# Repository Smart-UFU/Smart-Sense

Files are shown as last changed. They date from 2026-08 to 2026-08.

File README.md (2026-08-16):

# Smart-Sense

An open-source, low-cost, 3D-printed **absorbance photometer (colorimeter)** built around an
ESP32-S3 microcontroller and an AS7341 multi-channel spectral sensor.

You put a standard cuvette in the well, press a button, and the device does what a benchtop
colorimeter does: it measures a blank, measures five standards of known concentration, fits a
calibration curve (Beer–Lambert), and then reports the concentration of unknown samples — at up to
**8 wavelengths simultaneously** (415, 445, 480, 515, 555, 590, 630 and 680 nm).

Everything is configured from a web page served by the device itself. No app, no cables, no
software to install on your phone or laptop *after* the device is built.

> **This guide assumes no electronics or programming experience.** If you can follow a lab
> protocol, you can follow this. The only step that involves a computer is Part 2 (flashing), and it
> is a copy-and-click procedure.

---

## Contents

- [What you need](#what-you-need)
- [Part 1 — Printing the parts](#part-1--printing-the-parts)
- [Part 2 — Putting the code into the ESP32 (flashing)](#part-2--putting-the-code-into-the-esp32-flashing)
- [Part 3 — Using the device](#part-3--using-the-device)
- [Part 4 — How the code works](#part-4--how-the-code-works)
- [Known limitations](#known-limitations)
- [License](#license)

---

## What you need

### Electronics

| Item | Notes |
|---|---|
| **Adafruit Feather ESP32-S3 Reverse TFT** (PID 5691) | The brain + the 240×135 colour screen + the three buttons. The firmware is compiled specifically for this board. |
| **Adafruit AS7341 10-Channel Light/Color Sensor breakout** (PID 4698) | The detector. It also carries the white LED used as the light source. |
| **STEMMA QT / Qwiic cable** (JST-SH 4-pin) | Connects the sensor to the Feather. Both boards have the connector, so **no soldering is required**. |
| **USB-C cable capable of carrying data** | Needed once, to flash the firmware. See the warning in [Part 2](#step-5--connect-the-board). |
| *(optional)* 3.7 V LiPo battery with JST-PH connector | Makes the device portable. Not required. |

### Consumables

| Item | Notes |
|---|---|
| **Standard cuvettes, 12.5 × 12.5 mm outside, 10 mm path length** | The well in the printed case measures **12.7 mm square**, i.e. a standard cuvette plus 0.2 mm clearance. Plastic (PMMA/PS) cuvettes are fine for visible-range work. |

### Hardware

| Item | Notes |
|---|---|
| 4 × M3 self-tapping screws, 8–10 mm | The mounting holes in the printed parts are **Ø2.8 mm**, so a thread-forming M3 screw cuts its own thread in the plastic. M2.5 machine screws also work. |

### Tools

- A **3D printer** (FDM/filament, any common model) — or access to a printing service.
- A **computer running Windows, macOS or Linux** for the flashing step.

---

## Part 1 — Printing the parts

All three files are in the [`3D PIECES TO PRINT/`](3D%20PIECES%20TO%20PRINT) folder. Print **one of
each**.

| File | What it is | Size (mm) | Supports? |
|---|---|---|---|
| [`espCase.stl`](3D%20PIECES%20TO%20PRINT/espCase.stl) | Main body: holds the electronics and contains the cuvette well | 78.8 × 67.1 × 50.0 | **Yes** |
| [`bottomPlate.stl`](3D%20PIECES%20TO%20PRINT/bottomPlate.stl) | Flat lid that closes the bottom of the body | 78.9 × 69.1 × 2.0 | No |
| [`screenCover.stl`](3D%20PIECES%20TO%20PRINT/screenCover.stl) | Thin frame that sits over the display | 60.8 × 32.9 × 3.0 | No |

Total print time is roughly **5–7 hours** and uses about **80–110 g** of filament, depending on
your printer and settings.

### ⚠️ The single most important printing rule

**Print in opaque black filament.**

This is not cosmetic. The device measures how much light a sample absorbs. Any light that leaks
through the walls of the case and reaches the sensor without passing through the cuvette is *stray
light*, and stray light makes absorbance readings read low and non-linear at high concentrations —
exactly where you least want an error.

Concretely:
- Use **black** PLA or PETG. Not white, not natural, not translucent, not "galaxy" or sparkle.
- Use at least **3 perimeters (walls)** and **4 top/bottom layers** so the shell is genuinely
  light-tight.
- Use at least **20 % infill**. Higher is fine.

If you hold the finished body up to a bright lamp and can see any glow through the walls, print it
again with more walls.

### Recommended slicer settings

These work in Cura, PrusaSlicer, Bambu Studio, Orca — any slicer.

| Setting | Value |
|---|---|
| Material | PLA (easiest) or PETG (more heat-resistant) |
| Colour | **Black, opaque** |
| Layer height | 0.2 mm |
| Walls / perimeters | 3 or more |
| Top / bottom layers | 4 or more |
| Infill | 20–30 % |
| Supports | **Only for `espCase.stl`** — "support on build plate only" is enough |
| Brim | Optional; helps if your bed adhesion is marginal |
| Nozzle | 0.4 mm (standard) |

### ⚠️ Orient the parts before slicing

`espCase.stl` and `bottomPlate.stl` were exported **tilted 30° relative to the build plate**. If you
drop them into the slicer and hit "slice" without looking, they will print leaning over, need
enormous amounts of support, and come out badly.

Fix it in one click:

1. Load the part.
2. Use your slicer's **"Place on face"** tool (Cura: `Lay flat` / `Place on face`;
   PrusaSlicer and Orca: `Place on face`, keyboard shortcut `F`).
3. Click the **large flat face** of the part — for `espCase.stl` this is the big open bottom, for
   `bottomPlate.stl` it is either of the two large flat faces.

If your slicer has no such tool, rotate the part **+30° around the X axis** manually. When it is
correct, the reported height will be **50.0 mm** for `espCase.stl` and **2.0 mm** for
`bottomPlate.stl`.

`screenCover.stl` is already flat and needs no rotation — just lay it with its large flat face down.

### After printing

- Check that the **cuvette well is clear**. It should be a clean 12.7 mm square opening; a cuvette
  should slide in with a light friction fit and no rocking. Remove any support material or stringing
  from inside it with a hobby knife.
- Check that the **light-path openings** — the small windows in the walls on either side of the
  well — are clear and square. The LED shines in through one side and the sensor looks in from the
  other, so any debris or stringing here corrupts your readings directly.
- Do **not** sand or polish the inside of the case. A matte black interior is what you want.

---

## Part 2 — Putting the code into the ESP32 (flashing)

"Flashing" just means copying the program onto the microcontroller. You do it once. After that the
device runs standalone, and you never need the computer again.

We use **Visual Studio Code** (a free code editor from Microsoft) plus **PlatformIO** (a free
extension that handles compilers and libraries automatically). PlatformIO downloads everything else
it needs by itself.

> **Time required:** about 10 minutes of clicking, plus 5–15 minutes of unattended downloading the
> first time.

### Step 1 — Install Visual Studio Code

1. Go to **<https://code.visualstudio.com/>**.
2. Download the installer for your operating system and run it.
3. Accept the defaults. On Windows, ticking *"Add to PATH"* is helpful but not required.

### Step 2 — Install the PlatformIO extension

1. Open Visual Studio Code.
2. On the left-hand vertical bar, click the **Extensions** icon (four small squares, or press
   `Ctrl+Shift+X` — `Cmd+Shift+X` on macOS).
3. Type **`PlatformIO IDE`** in the search box.
4. Click **Install** on the entry published by *PlatformIO*.
5. Wait. The first install pulls down a Python environment and takes several minutes. A progress
   notification appears in the bottom-right corner.
6. **Restart VS Code** when it asks you to. When PlatformIO is ready, a small **ant/alien head icon**
   appears in the left-hand bar and a **house icon** appears in the blue status bar at the bottom.

### Step 3 — Download this project

**Option A (no Git needed):**
1. On the project's GitHub page, click the green **`Code`** button → **`Download ZIP`**.
2. Unzip it somewhere easy to find, e.g. your Desktop or Documents folder.

**Option B (if you have Git installed):**

```bash
git clone https://github.com/Smart-UFU/Smart-Sense.git
```

> **Avoid folder names with accents, spaces or special characters** in the full path
> (`C:\Users\João\Área de Trabalho\...`). The compiler toolchain occasionally chokes on them. A path
> like `C:\Smart-Sense` is safest.

### Step 4 — Open the project (this is where most people go wrong)

You must open the **`CODE`** folder — **not** the top-level `Smart-Sense` folder.

PlatformIO recognises a project by the presence of a `platformio.ini` file, and that file lives
inside `CODE/`.

1. In VS Code: **File → Open Folder…**
2. Navigate into `Smart-Sense` and select the folder named **`CODE`**.
3. Click **Select Folder** / **Open**.
4. If VS Code asks *"Do you trust the authors of the files in this folder?"*, click **Yes, I trust
   the authors** — otherwise PlatformIO cannot run.

You will know it worked when the blue status bar at the bottom of the window grows extra icons: a
**✓ (checkmark)**, a **→ (right arrow)**, a **🗑 (trash can)** and a **🔌 (plug)**.

**The first time you open it, PlatformIO will download the ESP32 compiler toolchain and the four
required libraries.** This is several hundred megabytes and can take 5–15 minutes on a normal
connection. Let it finish — the progress appears in the terminal panel at the bottom. You need an
internet connection for this step only.

### Step 5 — Connect the board

Plug the Feather into your computer with a **USB-C cable**.

> ⚠️ **The most common failure in this whole guide is a charge-only USB cable.** Many cheap USB-C
> cables (especially the ones bundled with phone chargers and power banks) carry power but no data.
> The board will light up and appear dead to the computer. If nothing is detected, **try a different
> cable first** before doing anything else.

The ESP32-S3 has native USB, so on Windows 10/11, macOS and Linux **no driver installation is
normally needed**. The board shows up on its own.

### Step 6 — Build and upload

1. Click the **✓ (checkmark)** icon in the bottom status bar. This is **Build** — it compiles the
   code without sending anything to the board. Wait for a green `SUCCESS` message in the terminal.
   (First build: a few minutes. Later builds: seconds.)
2. Click the **→ (right arrow)** icon. This is **Upload** — it compiles *and* copies the program to
   the board.
3. Watch the terminal. You want to see something like:

   ```
   Writing at 0x00010000... (100 %)
   Wrote 1048576 bytes ...
   Hash of data verified.
   Leaving...
   ================= [SUCCESS] Took 42.11 seconds =================
   ```

4. The screen on the Feather lights up and shows:

   ```
   Access the web
   interface at:
   192.168.4.1
   to send a setup
   ```

That's it. The device is programmed. **Unplug it from the computer** — from now on it runs from USB
power, a phone charger, a power bank or a LiPo battery.

### Troubleshooting

| Symptom | What to do |
|---|---|
| No COM port / no serial device found | Try a different USB-C cable (see the warning above). Then try a different USB port, preferably directly on the computer rather than through a hub. |
| `A fatal error occurred: Could not open ...` or upload just hangs | Put the board into bootloader mode by hand: **hold the `BOOT` button down, press and release `RESET`, then release `BOOT`.** Click Upload again immediately. Press `RESET` once when it finishes. |
| `Please specify 'upload_port'` | Several serial devices are present and PlatformIO cannot guess. Find the right port (Windows: Device Manager → Ports; macOS/Linux: `ls /dev/tty.*`) and add a line `upload_port = COM7` (or `/dev/ttyACM0`) under `[env:...]` in [`CODE/platformio.ini`](CODE/platformio.ini). |
| Library download fails / `HTTPClientError` | Check your internet connection and any corporate proxy or firewall, then run Build again. PlatformIO resumes where it left off. |
| Build fails immediately with "no project found" | You opened the wrong folder. Go back to [Step 4](#step-4--open-the-project-this-is-where-most-people-go-wrong) and open `CODE`, not `Smart-Sense`. |
| Screen stays black after upload | Press the `RESET` button on the Feather once. |
| Screen shows a red `Failed to initialize AS7341` | The sensor is not being seen over I²C. Check that the STEMMA QT cable is fully clicked into **both** boards. The firmware retries forever, so it recovers on its own once the cable is seated. |

---

## Part 3 — Using the device

Here is a full session, from power-on to a concentration reading.

### 1. Power on

Plug in USB power (or a battery). The screen shows the address of the built-in web interface,
normally `192.168.4.1`.

### 2. Connect to the device's Wi-Fi

The device creates its own Wi-Fi network. On your phone or laptop, connect to:

| | |
|---|---|
| **Network name (SSID)** | `Smart_Sense_Network` |
| **Password** | `smarteza` |

Your phone may warn you that this network has no internet access. That is expected — accept and stay
connected.

### 3. Open the configuration page

Open any browser and go to **<http://192.168.4.1>** (type the address exactly; do not search for
it).

You will see the Smart Sense setup form.

### 4. Fill in the setup

| Field | What to enter |
|---|---|
| **Gain** | Sensor amplification, 1× to 512×. Start with **64×**. |
| **LED current** | Brightness of the light source, 4–258 mA. Start with **50–100 mA**. |
| **First…Fifth Concentration** | The five known concentrations of your calibration standards, **in ascending order**, in whatever unit you like (mol/L, mg/L, ppm…). The device does not care about the unit — it reports the answer in the same one. Use a **decimal point**, not a comma. |
| **Channel selection** | The wavelength(s) you want to measure at. Pick the one closest to your analyte's λ<sub>max</sub>. |

**Selecting more than one wavelength:** hold `Ctrl` (Windows/Linux) or `Cmd` (macOS) while clicking,
or tap multiple entries on a phone. **You must select at least one** — if you select none, the
device will run through the whole procedure and display nothing.

The eight available channels:

| Channel | Wavelength | Colour it responds to |
|---|---|---|
| F1 | 415 nm | violet |
| F2 | 445 nm | indigo |
| F3 | 480 nm | blue |
| F4 | 515 nm | cyan/green |
| F5 | 555 nm | green |
| F6 | 590 nm | yellow |
| F7 | 630 nm | orange |
| F8 | 680 nm | red |

> Remember the complementary-colour rule: a **blue** solution absorbs in the **orange/red**, so you
> would measure it at 630 nm, not 480 nm.

Press **Send Setup**. The screen changes to `Setup OK`.

### 5. Run the blank (reference)

The screen asks you to *insert reference and press the button*.

1. Fill a cuvette with your **blank** — pure solvent, or the full reagent mixture without the
   analyte.
2. Put it in the well.
3. Press the **button labelled `D1`** on the Feather (the middle of the three buttons on the front
   edge).

The device takes 20 readings and stores the result as *I₀*. This takes roughly **10–15 seconds** per
measurement; the screen counts the readings as they happen.

### 6. Run the five standards

The screen asks for sample 1. For each of the five standards, in the **same order as the
concentrations you typed into the web form**:

1. Insert the cuvette.
2. Press `D1`.
3. Wait. The device shows the absorbance it calculated for each selected channel, for 3 seconds
   each.

After the fifth standard, the device fits the calibration line and displays, one channel at a time
for 5 seconds each:

```
Ch 630
a: 0.8412      <- slope
b: 0.0091      <- intercept
```

> 📝 **Write these numbers down.** They exist only in RAM and only on that screen. There is no
> logging, and cutting the power erases them.

### 7. Measure unknowns

The screen asks you to press the button for an unknown sample. Insert your unknown, press `D1`, and
after the measurement the device shows:

```
Ch 630 : 0.0247
```

That is the concentration, in the same unit you used for the standards, held on screen for 10
seconds.

You can keep measuring unknowns indefinitely — the device loops back to the "press the button for
another unknown sample" prompt. The calibration stays valid until you power the device off.

### Good practice for reliable numbers

- **Always insert the cuvette the same way round.** Cuvette walls are not perfectly identical; mark
  one face and keep it facing the LED.
- **Wipe the optical faces** of the cuvette with a lint-free tissue before every reading. A
  fingerprint is a large absorbance error.
- **Keep absorbances between about 0.1 and 1.0.** Below that, noise dominates; above it, the
  response goes non-linear. If your absorbances are too high, dilute. If they are too low, increase
  the gain and re-run the whole calibration.
- **Re-run the blank whenever you change gain, LED current, or wavelength.** All of those change
  what *I₀* means, so the old calibration is invalid.
- **Let the device warm up** for a minute or two before the blank. LED output drifts slightly as it
  heats.
- **Keep the lid on / room light constant.** This is a single-beam instrument with no dark-current
  correction; it cannot tell your analyte from the ceiling lights.

---

## Part 4 — How the code works

Everything lives in [`CODE/`](CODE):

| File | Role |
|---|---|
| [`platformio.ini`](CODE/platformio.ini) | Build configuration: which board, which framework, which libraries. |
| [`src/main.cpp`](CODE/src/main.cpp) | The entire firmware — sensor control, display, state machine, maths, web server. |
| [`include/webPage.h`](CODE/include/webPage.h) | The configuration web page (HTML + CSS + JavaScript) stored as one big string constant compiled into the firmware. |

### The build configuration

[`platformio.ini`](CODE/platformio.ini) declares the target board as
`adafruit_feather_esp32s3_reversetft`. That single line is what makes names like `TFT_CS`,
`TFT_BACKLITE` and `TFT_I2C_POWER` resolve to the correct pins — they come from the board definition,
not from the source code. **This is why the firmware will not work as-is on a different ESP32
board.**

It also pulls in four libraries automatically:

| Library | Purpose |
|---|---|
| `Adafruit ST7735 and ST7789 Library` | Drives the 240×135 colour display |
| `Adafruit AS7341` | Talks to the spectral sensor over I²C |
| `ESPAsyncWebServer` | Serves the configuration page without blocking the measurement loop |
| `ArduinoJson` | Declared as a dependency (the current code builds its JSON replies by hand) |

### Startup — `setup()`

[`main.cpp:81`](CODE/src/main.cpp#L81) runs once at power-on and does four things:

1. **Starts a Wi-Fi access point** (`WiFi.softAP`) named `Smart_Sense_Network`. The device *is* the
   network; it never joins yours. This is why it works in a lab with no infrastructure.
2. **Wakes up the display**: powers the backlight (`TFT_BACKLITE`) and the TFT/I²C power rail
   (`TFT_I2C_POWER` — on this board the sensor bus is switched, so forgetting this leaves the sensor
   invisible), then initialises a 135×240 panel rotated to landscape.
3. **Initialises the AS7341** in a `while(!as7341.begin())` loop — it retries forever and prints a
   red error rather than giving up, so plugging the cable in late still works.
   It then sets `ATIME = 100` and `ASTEP = 999`, which gives an integration time of
   `(100+1) × (999+1) × 2.78 µs ≈ 281 ms` per integration. Longer integration = more light collected
   = better signal-to-noise, at the cost of speed.
4. **Registers the web routes and starts the server.**

The button on GPIO 1 is configured as `INPUT_PULLDOWN` and read as active-**HIGH**, which matches the
`D1` button built into the Reverse TFT Feather.

### The web interface

Two routes are registered in `setupWebRoutes()` ([`main.cpp:406`](CODE/src/main.cpp#L406)):

- **`GET /`** returns the page from `webPage.h`.
- **`GET /setup?gain=…&current=…&concentration1=…&…&channels=415,630`** receives the configuration.

The handler rejects the request with HTTP 400 if any parameter is missing, stores the gain, LED
current and the five concentrations, then splits the comma-separated `channels` string into
`selectedChannels[]`.

It then calls `configureSensor()` ([`main.cpp:380`](CODE/src/main.cpp#L380)), which validates the LED
current against the 4–258 mA hardware range and maps the gain number onto the library's
`AS7341_GAIN_*` enum. If either is invalid the endpoint answers HTTP 500 and the device stays
waiting. Only on success does it set `config.isValid = true` — the single flag the main loop is
watching.

### The measurement state machine

`loop()` ([`main.cpp:98`](CODE/src/main.cpp#L98)) is not a linear program. It is a state machine:
every pass through the loop, it looks at `measureState` and does the small piece of work that state
calls for. This is what lets the web server stay responsive while the device waits for a button
press.

```mermaid
stateDiagram-v2
    [*] --> WAIT_SETUP
    WAIT_SETUP --> WAIT_BLANK: setup received from web page
    WAIT_BLANK --> MEASURING_BLANK: button pressed
    MEASURING_BLANK --> WAIT_BUTTON: I0 stored in blankReadings[]
    WAIT_BUTTON --> MEASURING: button pressed
    MEASURING --> WAIT_BUTTON: fewer than 5 standards done
    MEASURING --> WAIT_UNKNOWN_SAMPLE: 5 standards done, curve fitted
    WAIT_UNKNOWN_SAMPLE --> MEASURE_UNKNOWN_SAMPLE: button pressed
    MEASURE_UNKNOWN_SAMPLE --> WAIT_UNKNOWN_SAMPLE: concentration displayed
```

Note the last transition: after an unknown sample the device returns to
`WAIT_UNKNOWN_SAMPLE`, never back to calibration. One calibration, unlimited unknowns.

### Taking one reading — `performSingleMeasurement()`

[`main.cpp:232`](CODE/src/main.cpp#L232) is the heart of the instrument, and it is the same routine
for the blank, the standards and the unknowns:

1. **Turn the LED on** and wait 100 ms for it to stabilise.
2. **Take 20 complete readings** of all channels (`READINGS_PER_SAMPLE = 20`), 50 ms apart.
3. For each reading, **pick out only the channels you selected.** The sensor's `readAllChannels()`
   returns 12 values, and the mapping is not a straight 0–7 — the array contains duplicated
   clear/NIR entries in the middle. The `switch` statement handles this:

   | Wavelength | Index in the raw array |
   |---|---|
   | 415 nm (F1) | 0 |
   | 445 nm (F2) | 1 |
   | 480 nm (F3) | 2 |
   | 515 nm (F4) | 3 |
   | 555 nm (F5) | **6** |
   | 590 nm (F6) | **7** |
   | 630 nm (F7) | **8** |
   | 680 nm (F8) | **9** |

4. **Turn the LED off** — important, because leaving it on would heat the sensor and shift readings.
5. **Reduce the 20 readings per channel to one number** via `calculateAverage()`.

The whole routine takes roughly **10–15 seconds**, most of it spent on the 20 integrations.

### Why the average is not a plain average — `calculateAverage()`

[`main.cpp:452`](CODE/src/main.cpp#L452) does something more careful than adding up 20 numbers and
dividing by 20. It:

1. **Sorts** the 20 readings from smallest to largest,
2. **Discards the bottom quarter and the top quarter** (indices 0–4 and 15–19),
3. **Averages the middle 10 only.**

This is an **interquartile (trimmed) mean**. A single bubble in the cuvette, a flicker in the LED, or
a stray reflection produces one wild reading; a plain mean would carry that error into your result,
while a trimmed mean throws it away entirely. It is the same reasoning behind discarding outliers in
a set of titration replicates.

### From counts to absorbance

The sensor reports raw counts — a number proportional to how much light hit it — not absorbance. The
conversion is the Beer–Lambert law, applied at [`main.cpp:153`](CODE/src/main.cpp#L153):

$$A = -\log_{10}\left(\frac{I}{I_0}\right)$$

where **I₀** is the blank reading (`blankReadings[]`) and **I** is the sample reading. The guard
`if (blankReadings[i] > 0 && sampleResults[i] > 0)` prevents a division by zero or a logarithm of
zero from producing garbage; in that case absorbance is recorded as 0.

This is done independently for each channel you selected, so measuring at four wavelengths gives you
four independent absorbance values from one press of the button.

### Fitting the calibration curve

Once the fifth standard is measured, `calculateLinearRegressionPerChannel()`
([`main.cpp:277`](CODE/src/main.cpp#L277)) performs a **least-squares linear regression** for each
channel separately, with

- **x = concentration** (the five values you typed into the web page)
- **y = absorbance** (the five values the device just measured)

producing the familiar line

$$A = a \cdot C + b$$

using the standard closed-form expressions

$$a = \frac{n\sum xy - \sum x \sum y}{n\sum x^2 - (\sum x)^2}, \qquad b = \frac{\sum y \sum x^2 - \sum x \sum xy}{n\sum x^2 - (\sum x)^2}$$

The slope **a** is the analytical sensitivity (and, if your concentrations are in mol/L and your path
length is 1 cm, it is the molar absorptivity ε). The intercept **b** should be close to zero for a
well-behaved blank — a large intercept is a hint that something is wrong with your blank or that
stray light is reaching the sensor.

The coefficients are stored in `a_reg[]` and `b_reg[]` and displayed by
`showRegressionsOnDisplay()`.

### Back to concentration

For an unknown sample, [`main.cpp:206`](CODE/src/main.cpp#L206) measures its absorbance the same way
and then inverts the calibration line:

$$C = \frac{A - b}{a}$$

with a guard against `a == 0` (which would mean the calibration failed — for example, five standards
that all read the same absorbance).

### Numbers you might want to change

| What | Where | Effect |
|---|---|---|
| Wi-Fi name and password | [`main.cpp:19-20`](CODE/src/main.cpp#L19) | Useful if several devices run in the same room |
| Readings averaged per measurement | `READINGS_PER_SAMPLE`, [`main.cpp:56`](CODE/src/main.cpp#L56) | More = slower but less noisy |
| Integration time | `setATIME` / `setASTEP`, [`main.cpp:350`](CODE/src/main.cpp#L350) | More = more light collected per reading |
| Number of calibration standards | Hard-coded as **5** in several places | Changing it requires editing the web page, the `MeasurementConfig` struct, the regression function and the loop counter together |

After any edit, repeat [Step 6](#step-6--build-and-upload) — Build, then Upload.

---

## Known limitations

Stated plainly, so you know what this instrument is and is not:

- **Nothing is saved.** Calibration coefficients and results live in RAM. Power off, and they are
  gone. Photograph the screen or write the numbers down.
- **Results appear only on the small display.** There is no data logging, no CSV export, and no
  results page in the web interface — the web page is for input only.
- **Exactly five calibration standards**, no more, no fewer. There is no way to skip a standard or
  add a sixth without editing the code.
- **No goodness-of-fit statistic.** The device reports the slope and intercept but not R², so it
  cannot tell you that your calibration was poor. Plot your five points yourself if the numbers look
  strange.
- **No dark-current / ambient-light correction.** The blank is measured with the LED on, so it
  includes ambient light at that moment. If room lighting changes between the blank and the sample,
  the reading shifts. Keep conditions constant.
- **Single beam.** LED drift between the blank and a later sample appears directly as an error.
  Re-blank periodically during long sessions.
- **The channel selector accepts zero channels.** If you forget to select a wavelength, the whole
  procedure runs and displays nothing at the end.
- **The web interface has no authentication.** Anyone within Wi-Fi range who knows the password can
  reconfigure the device. It is designed for a benchtop, not a network.

---

## License

MIT — see [LICENSE](LICENSE). Copyright (c) 2026 Smart-UFU.

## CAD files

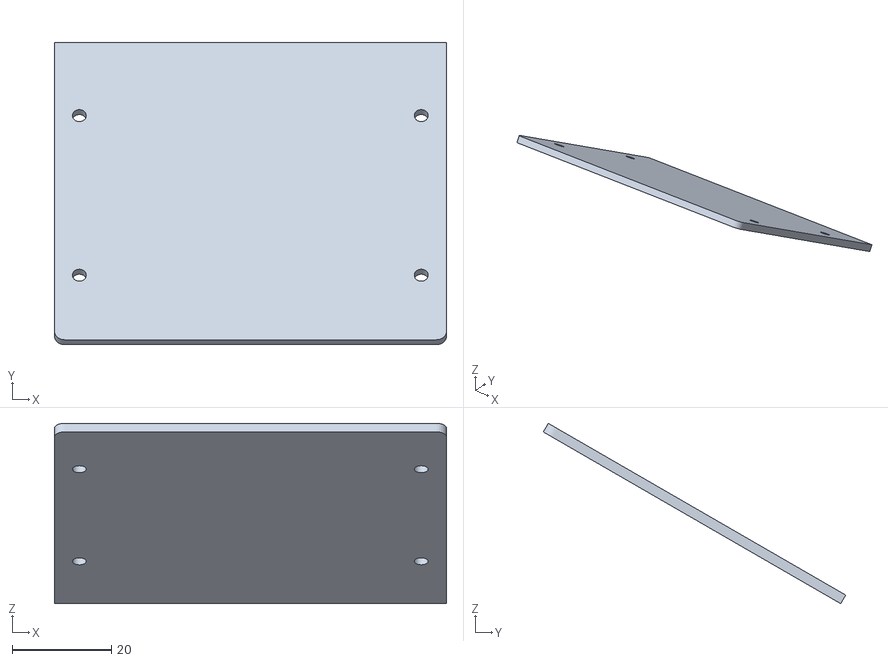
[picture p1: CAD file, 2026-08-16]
3D PIECES TO PRINT/bottomPlate.stl
78.9 x 60.9 x 36.3

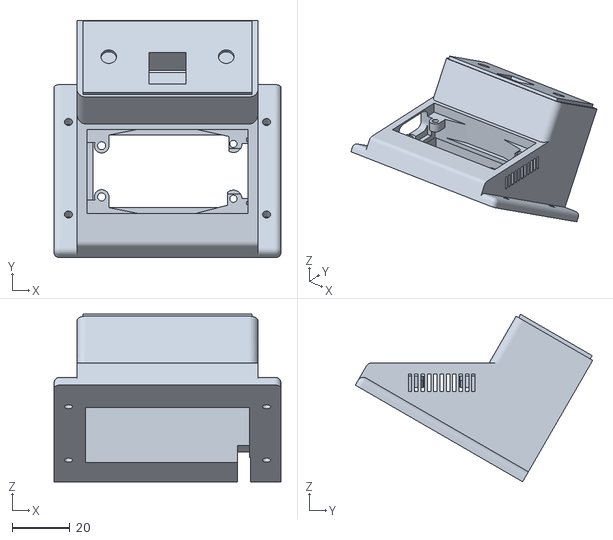
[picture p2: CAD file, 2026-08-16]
3D PIECES TO PRINT/espCase.stl
78.8 x 82.4 x 58.2

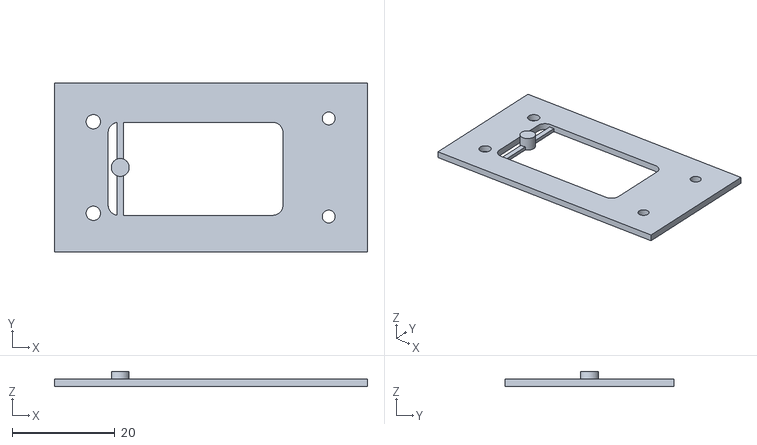
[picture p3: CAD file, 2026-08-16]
3D PIECES TO PRINT/screenCover.stl
60.8 x 32.9 x 3.00

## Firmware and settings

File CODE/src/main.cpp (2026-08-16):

#include <Arduino.h>
#include <Adafruit_GFX.h>    // Core graphics library
#include <Adafruit_ST7789.h>
#include <SPI.h>
#include <Adafruit_AS7341.h>
#include <ESPAsyncWebServer.h>
#include "webPage.h"
#include <math.h> // Added for the log10 function

// Configuration constants
#define MIN_LED_CURRENT 4
#define MAX_LED_CURRENT 258
#define MIN_GAIN 1
#define MAX_GAIN 512

#define BUTTON_PIN 1  // GPIO1

// WiFi configuration
const char* ssid = "Smart_Sense_Network";
const char* password = "smarteza";

// Use dedicated hardware SPI pins
Adafruit_ST7789 tft = Adafruit_ST7789(TFT_CS, TFT_DC, TFT_RST);
Adafruit_AS7341 as7341;

struct MeasurementConfig {
    uint16_t gain = 1;
    uint16_t current = 100;
    float concentration_values[5];
    bool isValid = false;
};

// States of the measurement state machine
enum MeasurementState {
    WAIT_SETUP,
    WAIT_BLANK,           // Waits for the reference (blank) measurement
    MEASURING_BLANK,      // Measures the reference (blank)
    WAIT_BUTTON,
    MEASURING,
    WAIT_UNKNOWN_SAMPLE,
    MEASURE_UNKNOWN_SAMPLE
};

MeasurementState measureState = WAIT_SETUP;
uint8_t currentSample = 0;
bool lastButtonState = LOW;
unsigned long lastDebounceTime = 0;
const unsigned long debounceDelay = 50; // milliseconds

MeasurementConfig config;
AsyncWebServer server(80);

// Channel variables
#define MAX_CHANNELS 8
#define NUM_CHANNELS 8
#define READINGS_PER_SAMPLE 20
uint16_t selectedChannels[MAX_CHANNELS];
uint8_t numSelectedChannels = 0;

// Data storage variables
float blankReadings[MAX_CHANNELS];          // Stores the reference (blank) reading
float sampleAbsorbances[5][MAX_CHANNELS];   // Stores the absorbance of each sample

// Global arrays holding the regression coefficients (y = ax + b)
float a_reg[MAX_CHANNELS]; // Slope 'a'
float b_reg[MAX_CHANNELS]; // Intercept 'b'

// Function prototypes
void initializeDisplay();
void initializeSensor();
void writeTextToDisplay(const String& text, uint16_t color, uint8_t size, uint16_t x, uint16_t y, uint16_t durationMs);
void writeTextCenteredToDisplay(const String& text, uint16_t color, uint8_t size, uint16_t durationMs);
bool configureSensor();
void setupWebRoutes();
void clearDisplay();
float calculateAverage(uint16_t readings[], int size);
void performSingleMeasurement(float* resultArray);
void showRegressionsOnDisplay();
void calculateLinearRegressionPerChannel(float x_values[5], float y_values[5][MAX_CHANNELS], uint8_t numChannels, float* a_out, float* b_out);

void setup(void) {
  // WiFi configuration
  WiFi.softAP(ssid, password);
  // Initialize the display and the sensor
  initializeDisplay();
  initializeSensor();
  setupWebRoutes();
  server.begin();

  pinMode(BUTTON_PIN, INPUT_PULLDOWN);

  writeTextToDisplay("Access the web", ST77XX_WHITE, 2, 10, 20, 0);
  writeTextToDisplay("interface at:", ST77XX_WHITE, 2, 10, 40, 0);
  writeTextToDisplay(WiFi.softAPIP().toString(), ST77XX_CYAN, 2, 10, 60, 0);
  writeTextToDisplay("to send a setup", ST77XX_WHITE, 2, 10, 80, 0);
}

void loop() {
  // 1. Waits for the configuration sent from the web page
  if (config.isValid && measureState == WAIT_SETUP) {
    clearDisplay();
    writeTextToDisplay("Setup OK", ST77XX_GREEN, 2, 10, 30, 0);
    writeTextToDisplay("Insert reference", ST77XX_CYAN, 2, 10, 50, 0);
    writeTextToDisplay("and press the", ST77XX_CYAN, 2, 10, 70, 0);
    writeTextToDisplay("button", ST77XX_CYAN, 2, 10, 90, 0);
    measureState = WAIT_BLANK;
  }

  // 2. Waits for the button to measure the REFERENCE (blank)
  if (measureState == WAIT_BLANK) {
      if (digitalRead(BUTTON_PIN) == HIGH) {
          measureState = MEASURING_BLANK;
          delay(300); // Debounce
      }
  }

  // 3. Performs the REFERENCE (blank) measurement
  if (measureState == MEASURING_BLANK) {
      clearDisplay();
      writeTextCenteredToDisplay("Measuring Reference...", ST77XX_YELLOW, 2, 3000);
      performSingleMeasurement(blankReadings); // Stores the reference reading

      writeTextToDisplay("reference measured", ST77XX_GREEN, 2, 10, 30, 0);
      writeTextToDisplay("Insert sample 1", ST77XX_CYAN, 2, 10, 50, 0);
      writeTextToDisplay("and press the", ST77XX_CYAN, 2, 10, 70, 0);
      writeTextToDisplay("button", ST77XX_CYAN, 2, 10, 90, 0);
      measureState = WAIT_BUTTON;
      currentSample = 0;
  }

  // 4. Waits for the button for the calibration samples
  if (measureState == WAIT_BUTTON) {
    if (digitalRead(BUTTON_PIN) == HIGH) {
      measureState = MEASURING;
      delay(300); // Debounce
    }
  }

  // 5. Measures the 5 calibration samples
  if (measureState == MEASURING) {
    clearDisplay();
    writeTextToDisplay("Measuring sample", ST77XX_YELLOW, 2, 10, 20, 0);
    writeTextToDisplay("number " + String(currentSample + 1), ST77XX_YELLOW, 2, 10, 40, 0);
    delay(3000); // Time for the user to read the message

    float sampleResults[MAX_CHANNELS];
    performSingleMeasurement(sampleResults);

    // Calculates the absorbance and saves the results
    for (uint8_t i = 0; i < numSelectedChannels; i++) {
        // Absorbance calculation: A = -log10(I / I0)
        // I = sampleResults[i], I0 = blankReadings[i]
        if (blankReadings[i] > 0 && sampleResults[i] > 0) {
            float transmittance = sampleResults[i] / blankReadings[i];
            sampleAbsorbances[currentSample][i] = -log10(transmittance);
        } else {
            sampleAbsorbances[currentSample][i] = 0; // Avoids division by zero or log of zero
        }

        // Shows the calculated absorbance
        writeTextToDisplay("Ch " + String(selectedChannels[i]) + " Abs: " + String(sampleAbsorbances[currentSample][i], 3),
                         ST77XX_WHITE, 2, 10, 10 + i * 15, 3000);
    }

    currentSample++;
    if (currentSample < 5) { // If the 5 samples have not been measured yet
      clearDisplay();
      writeTextToDisplay("Insert sample " + String(currentSample + 1), ST77XX_WHITE, 2, 10, 40, 0);
      writeTextToDisplay("and press the", ST77XX_WHITE, 2, 10, 60, 0);
      writeTextToDisplay("button", ST77XX_WHITE, 2, 10, 80, 0);
      measureState = WAIT_BUTTON;
    } else { // If all 5 samples have already been measured
      clearDisplay();
      writeTextCenteredToDisplay("Calculating curve...", ST77XX_CYAN, 2, 2000);
      showRegressionsOnDisplay(); // Calculates and shows the a and b values for each channel
      writeTextToDisplay("Calibration Done!", ST77XX_GREEN, 2, 10, 40, 2000);

      clearDisplay();
      writeTextToDisplay("Press the button", ST77XX_WHITE, 2, 10, 20, 0);
      writeTextToDisplay("for unknown sample", ST77XX_WHITE, 2, 10, 40, 0);
      measureState = WAIT_UNKNOWN_SAMPLE;
    }
  }

  // 6. Waits for the button to measure an unknown sample
  if (measureState == WAIT_UNKNOWN_SAMPLE) {
    if (digitalRead(BUTTON_PIN) == HIGH) {
      measureState = MEASURE_UNKNOWN_SAMPLE;
      delay(300);
    }
  }

  // 7. Measures the unknown sample and calculates its concentration
  if (measureState == MEASURE_UNKNOWN_SAMPLE) {
    clearDisplay();
    writeTextToDisplay("Measuring unknown", ST77XX_YELLOW, 2, 10, 20, 0);
    writeTextToDisplay("sample...", ST77XX_YELLOW, 2, 10, 40, 0);
    delay(3000);

    float unknownRawResults[MAX_CHANNELS];
    performSingleMeasurement(unknownRawResults);

    clearDisplay();
    writeTextCenteredToDisplay("Calculating...", ST77XX_CYAN, 2, 1000);

    for (uint8_t i = 0; i < numSelectedChannels; i++) {
      // Calculates the concentration from the absorbance
      float unknownAbsorbance = 0;
      if (blankReadings[i] > 0 && unknownRawResults[i] > 0) {
        unknownAbsorbance = -log10(unknownRawResults[i] / blankReadings[i]);
      }

      // Calculates the concentration using the inverted line equation: x = (y - b) / a
      float concentration = 0;
      if (a_reg[i] != 0) { // Avoids division by zero
          concentration = (unknownAbsorbance - b_reg[i]) / a_reg[i];
      }

      clearDisplay();
      String concStr = "Ch " + String(selectedChannels[i]) + " : " + String(concentration, 4);
      writeTextToDisplay(concStr, ST77XX_WHITE, 2, 10, 50, 10000);
    }

    clearDisplay();
    writeTextToDisplay("Press the button", ST77XX_WHITE, 2, 10, 20, 0);
    writeTextToDisplay("for another", ST77XX_WHITE, 2, 10, 40, 0);
    writeTextToDisplay("unknown sample", ST77XX_WHITE, 2, 10, 60, 0);
    measureState = WAIT_UNKNOWN_SAMPLE;
  }
}

void performSingleMeasurement(float* resultArray) {
    as7341.enableLED(true);
    delay(100); // Short delay to let the LED stabilize

    uint16_t readings[READINGS_PER_SAMPLE][NUM_CHANNELS] = {0};

    for (int i = 0; i < READINGS_PER_SAMPLE; i++) {
        uint16_t rawReadings[12];
        if (as7341.readAllChannels(rawReadings)) {
            for (int j = 0; j < numSelectedChannels; j++) {
                int idx = -1;
                switch(selectedChannels[j]) {
                    case 415: idx = 0; break; // F1
                    case 445: idx = 1; break; // F2
                    case 480: idx = 2; break; // F3
                    case 515: idx = 3; break; // F4
                    case 555: idx = 6; break; // F5
                    case 590: idx = 7; break; // F6
                    case 630: idx = 8; break; // F7
                    case 680: idx = 9; break; // F8
                }
                if (idx >= 0) {
                    readings[i][j] = rawReadings[idx];
                }
            }
        }
        delay(50);
        clearDisplay(); // Clears the screen for each reading
        writeTextCenteredToDisplay("Reading " + String(i + 1) + " done", ST77XX_WHITE, 2, 0);
    }

     as7341.enableLED(false);

    // Calculate the averages for each selected channel
    for (int channel = 0; channel < numSelectedChannels; channel++) {
        uint16_t channelReadings[READINGS_PER_SAMPLE];
        for (int i = 0; i < READINGS_PER_SAMPLE; i++) {
            channelReadings[i] = readings[i][channel];
        }
        resultArray[channel] = calculateAverage(channelReadings, READINGS_PER_SAMPLE);
    }
    clearDisplay();
}

// Computes the regression for X = Concentration, Y = Absorbance
void calculateLinearRegressionPerChannel(float x_values[5], float y_values[5][MAX_CHANNELS], uint8_t numChannels, float* a_out, float* b_out) {
    for (uint8_t channel = 0; channel < numChannels; channel++) {
        float sumX = 0, sumY = 0, sumXY = 0, sumXX = 0;
        int n = 5;
        for (uint8_t i = 0; i < n; i++) {
            float x = x_values[i];
            float y = y_values[i][channel];
            sumX += x;
            sumY += y;
            sumXY += x * y;
            sumXX += x * x;
        }
        float denom = n * sumXX - sumX * sumX;
        if (denom != 0) {
            a_out[channel] = (n * sumXY - sumX * sumY) / denom; // 'a' (slope)
            b_out[channel] = (sumY * sumXX - sumX * sumXY) / denom; // 'b' (intercept)
        } else {
            a_out[channel] = 0;
            b_out[channel] = 0;
        }
    }
}

void showRegressionsOnDisplay() {
    // Passes the concentration and absorbance values to the regression function
    calculateLinearRegressionPerChannel(config.concentration_values, sampleAbsorbances, numSelectedChannels, a_reg, b_reg);

    for (uint8_t i = 0; i < numSelectedChannels; i++) {
        clearDisplay();
        String channelStr = "Ch " + String(selectedChannels[i]);
        String aStr = "a: " + String(a_reg[i], 4); // slope
        String bStr = "b: " + String(b_reg[i], 4); // intercept
        writeTextToDisplay(channelStr, ST77XX_WHITE, 2, 10, 20, 0);
        writeTextToDisplay(aStr, ST77XX_YELLOW, 2, 10, 50, 0);
        writeTextToDisplay(bStr, ST77XX_YELLOW, 2, 10, 80, 0);
        delay(5000);
    }
    clearDisplay();
}

void clearDisplay(){
    tft.fillScreen(ST77XX_BLACK);
}

void initializeDisplay() {
  // Turn on the display backlight
  pinMode(TFT_BACKLITE, OUTPUT);
  digitalWrite(TFT_BACKLITE, HIGH);

  // Turn on the power for TFT / I2C
  pinMode(TFT_I2C_POWER, OUTPUT);
  digitalWrite(TFT_I2C_POWER, HIGH);
  delay(10);

  // Initialize the TFT display
  tft.init(135, 240);
  tft.setRotation(3);
  tft.fillScreen(ST77XX_BLACK);
  tft.setTextWrap(true);
}

void initializeSensor() {
  // Initialize the AS7341 sensor
  while(!as7341.begin()) {
    writeTextToDisplay("Failed to initialize AS7341", ST77XX_RED, 2, 10, 40, 0);
    delay(1000);
  }

  clearDisplay();

  writeTextToDisplay("AS7341 initialized", ST77XX_GREEN, 2, 10, 40, 5000);

  // Configure sensor parameters
  as7341.setATIME(100);
  as7341.setASTEP(999);
}

void writeTextToDisplay(const String& text, uint16_t color, uint8_t size, uint16_t x, uint16_t y, uint16_t durationMs) {
  tft.setTextColor(color);
  tft.setTextSize(size);
  tft.setCursor(x, y);
  tft.println(text);
  if (durationMs > 0) {
    delay(durationMs);
    tft.fillScreen(ST77XX_BLACK); // Clears the screen after the delay
  }
}

void writeTextCenteredToDisplay(const String& text, uint16_t color, uint8_t size, uint16_t durationMs) {
  tft.setTextColor(color);
  tft.setTextSize(size);
  int16_t x1, y1;
  uint16_t w, h;
  tft.getTextBounds(text, 0, 0, &x1, &y1, &w, &h);
  uint16_t x = (tft.width() - w) / 2;
  uint16_t y = (tft.height() - h) / 2;
  tft.setCursor(x, y);
  tft.println(text);
  if (durationMs > 0) {
    delay(durationMs);
  }
}

bool configureSensor() {
    if(config.current < MIN_LED_CURRENT || config.current > MAX_LED_CURRENT) {
        writeTextCenteredToDisplay("Invalid LED current", ST77XX_RED, 2, 2000);
        return false;
    }
    as7341.setLEDCurrent(config.current);
    as7341_gain_t gainSetting;
    switch (config.gain) {
        case 1: gainSetting = AS7341_GAIN_1X; break;
        case 2: gainSetting = AS7341_GAIN_2X; break;
        case 4: gainSetting = AS7341_GAIN_4X; break;
        case 8: gainSetting = AS7341_GAIN_8X; break;
        case 16: gainSetting = AS7341_GAIN_16X; break;
        case 32: gainSetting = AS7341_GAIN_32X; break;
        case 64: gainSetting = AS7341_GAIN_64X; break;
        case 128: gainSetting = AS7341_GAIN_128X; break;
        case 256: gainSetting = AS7341_GAIN_256X; break;
        case 512: gainSetting = AS7341_GAIN_512X; break;
        default:
        writeTextCenteredToDisplay("Invalid gain setting", ST77XX_RED, 2, 2000);
        return false;
    }
    as7341.setGain(gainSetting);
    return true;
}

void setupWebRoutes() {
    server.on("/", HTTP_GET, [](AsyncWebServerRequest *request) {
        request->send(200, "text/html", webpage);
    });

    server.on("/setup", HTTP_GET, [](AsyncWebServerRequest *request) {
        if (!request->hasParam("gain") || !request->hasParam("current") ||
            !request->hasParam("concentration1") || !request->hasParam("concentration2") ||
            !request->hasParam("concentration3") || !request->hasParam("concentration4") ||
            !request->hasParam("concentration5") || !request->hasParam("channels")) {
            request->send(400, "application/json", "{\"error\":\"Missing parameters\"}");
            return;
        }

        config.gain = request->getParam("gain")->value().toInt();
        config.current = request->getParam("current")->value().toInt();
        // Stores the concentration values
        config.concentration_values[0] = request->getParam("concentration1")->value().toFloat();
        config.concentration_values[1] = request->getParam("concentration2")->value().toFloat();
        config.concentration_values[2] = request->getParam("concentration3")->value().toFloat();
        config.concentration_values[3] = request->getParam("concentration4")->value().toFloat();
        config.concentration_values[4] = request->getParam("concentration5")->value().toFloat();

        // Parse the selected channels
        String channelsStr = request->getParam("channels")->value();
        numSelectedChannels = 0;
        int lastIdx = 0;
        while (numSelectedChannels < MAX_CHANNELS) {
            int commaIdx = channelsStr.indexOf(',', lastIdx);
            String ch = (commaIdx == -1) ? channelsStr.substring(lastIdx) : channelsStr.substring(lastIdx, commaIdx);
            if (ch.length() > 0) selectedChannels[numSelectedChannels++] = ch.toInt();
            if (commaIdx == -1) break;
            lastIdx = commaIdx + 1;
        }

        if (!configureSensor()) {
            request->send(500, "application/json", "{\"error\":\"Sensor configuration failed\"}");
            writeTextToDisplay("Sensor config failed", ST77XX_RED, 2, 10, 10, 2000);
            return;
        }
        config.isValid = true;

        request->send(200, "application/json", "{\"status\":\"success\"}");
    });
}

float calculateAverage(uint16_t readings[], int size) {
  for (int i = 0; i < size - 1; i++) {
    for (int j = i + 1; j < size; j++) {
      if (readings[j] < readings[i]) {
        uint16_t temp = readings[i];
        readings[i] = readings[j];
        readings[j] = temp;
      }
    }
  }

  int firstQuartile = size / 4;
  int lastQuartile = firstQuartile * 3;
  float sum = 0.0;
  int count = 0;
  for (int i = firstQuartile; i < lastQuartile; i++) {
    sum += readings[i];
    count++;
  }
  return count > 0 ? sum / count : 0;
}
